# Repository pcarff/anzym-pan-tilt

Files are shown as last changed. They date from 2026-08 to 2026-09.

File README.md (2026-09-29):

# Dual-Axis Pan-Tilt (Alt-Azimuth) Stepper Controller

A professional dual-axis stepper motor controller and real-time dashboard for Pan-Tilt (Azimuth-Elevation) tracking and positioning systems. Built for Arduino Uno interfacing with **AutomationDirect SureStep STP-DRV-6575** microstepping drives.

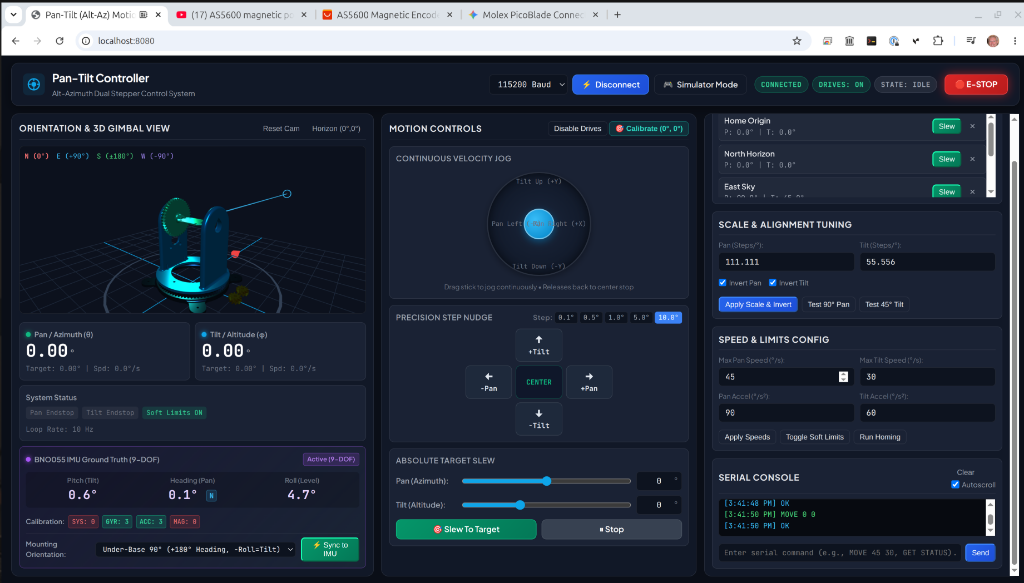
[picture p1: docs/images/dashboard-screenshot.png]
Pan-Tilt Controller Real-Time Dashboard


---

## 🌟 Key Features

- **Firmware (Arduino C++)**:
  - Smooth trapezoidal acceleration and velocity profiling.
  - Open-loop step position tracking with engineering degree ($^\circ$) unit conversion.
  - Continuous velocity jogging (interactive joystick control).
  - Configurable soft travel limits (prevent cable wrap / mechanical collisions).
  - Limit switch homing state machine with debounce.
  - Extensible sensor hooks for I2C IMU (MPU6050, BNO055) and auxiliary inputs.
  - 115200 baud ASCII serial protocol with high-frequency (10–20 Hz) telemetry streaming.
- **Dashboard (Web & Web Serial)**:
  - Direct USB Web Serial connection (no backend server required!).
  - Built-in **Simulator Mode** for instant interactive testing without hardware.
  - Interactive **3D Gimbal Visualizer** (Three.js) showing live physical orientation, compass heading, and target reticle.
  - **📐 2-Point Manual Calibration Studio**: Interactive visual wizard to position start reference, zero step counter, jog/nudge to target angle, calculate steps/deg & gear ratio, cross-check with BNO055 IMU ground truth, and apply live to controller RAM without resetting.
  - **Multi-Trial Averaging**: Run multiple calibration passes, compute mean scale & standard deviation ($\pm\sigma$), and apply statistically filtered values.
  - **2D Virtual Joystick** for smooth velocity jogging.
  - **Precision Step Nudge D-Pad** ($0.1^\circ, 0.5^\circ, 1.0^\circ, 5.0^\circ, 10.0^\circ$).
  - **Absolute Target Slew** with sliders and direct degree inputs.
  - **Waypoint & Preset Manager** with persistent browser storage.
  - **Integrated Serial Terminal** with command history.
  - Instant Emergency Stop (`E-STOP`).

---

## 🔌 Hardware Wiring Guide (STP-DRV-6575 & Arduino Uno)

### Pin Mapping Table

| Arduino Uno Pin | Function | STP-DRV-6575 Terminal | Notes |
|---|---|---|---|
| `D2` | Pan STEP (Pulse) | **STEP+** (Drive 1 - Pan) | 5V Step Pulse (Active High) |
| `D3` | Pan DIR (Direction) | **DIR+** (Drive 1 - Pan) | High = CW, Low = CCW |
| `D4` | Pan EN (Enable) | **EN+** (Drive 1 - Pan) | High = Energized, Low = Free |
| `D5` | Tilt STEP (Pulse) | **STEP+** (Drive 2 - Tilt) | 5V Step Pulse (Active High) |
| `D6` | Tilt DIR (Direction) | **DIR+** (Drive 2 - Tilt) | High = Up, Low = Down |
| `D7` | Tilt EN (Enable) | **EN+** (Drive 2 - Tilt) | High = Energized, Low = Free |
| `GND` | Common Ground | **STEP-**, **DIR-**, **EN-** (Both Drives) | Common Cathode wiring |
| `D8` | Pan Limit Switch | Switch NO $\to$ `D8`, Common $\to$ `GND` | Internal pull-up enabled |
| `D9` | Tilt Limit Switch | Switch NO $\to$ `D9`, Common $\to$ `GND` | Internal pull-up enabled |
| `A4` (SDA) | I2C Data | Future IMU / Sensors SDA | Optional |
| `A5` (SCL) | I2C Clock | Future IMU / Sensors SCL | Optional |

### STP-DRV-6575 DIP Switch Settings
- **Current (Amps)**: Set switches according to your stepper motor rated phase current.
- **Microstepping**: Recommended **8x microstepping** (1600 steps/rev) or **16x microstepping** (3200 steps/rev).
- Match the microstepping in [`firmware/PanTiltController/Config.h`](file:///workspaces/anzym_altaz_ws/firmware/PanTiltController/Config.h) (`PAN_MICROSTEPS` and `TILT_MICROSTEPS`).

---

## 🚀 Getting Started

### 1. Flashing the Arduino Firmware
1. Open the Arduino IDE.
2. Open [`firmware/PanTiltController/PanTiltController.ino`](file:///workspaces/anzym_altaz_ws/firmware/PanTiltController/PanTiltController.ino).
3. Select **Board**: `Arduino Uno` and choose your serial port.
4. Click **Upload**.

### 2. Launching the Dashboard
The dashboard runs entirely in the browser using the **Web Serial API** (Google Chrome, Microsoft Edge, Opera).

To run locally:
```bash
# Option A: Python simple HTTP server
python3 -m http.server 8080 --directory dashboard

# Option B: Node.js npx serve
npx serve dashboard
```
Then open `http://localhost:8080` in Chrome/Edge.

- Click **"Connect Serial"** to connect to your Arduino Uno.
- Or click **"Simulator Mode"** to test all 3D visuals, joystick controls, presets, and commands immediately without physical hardware!

---

## 📡 Serial Command Reference

Baud Rate: `115200` | Line Ending: `\n` or `\r\n`

| Command | Example | Description |
|---|---|---|
| `MOVE <pan> <tilt>` | `MOVE 45.0 15.0` | Move to absolute angles in degrees |
| `MOVEREL <d_pan> <d_tilt>` | `MOVEREL 1.0 -2.5` | Move relative by delta degrees |
| `JOG <p_spd> <t_spd>` | `JOG 20.0 -10.0` | Continuous velocity jog in deg/s (`JOG 0 0` to stop) |
| `STOP` | `STOP` | Decelerate to smooth stop |
| `ESTOP` | `ESTOP` | Immediate emergency stop and disable |
| `ENABLE` / `DISABLE` | `ENABLE` | Energize or de-energize stepper coils |
| `ZERO` | `ZERO` | Reset current position as $(0^\circ, 0^\circ)$ |
| `SETPOS <pan> <tilt>` | `SETPOS 0 45` | Set custom coordinate reference |
| `HOME [ALL\|PAN\|TILT]` | `HOME ALL` | Execute limit switch homing routine |
| `SET SPEED <p> <t>` | `SET SPEED 60 40` | Set max velocity in deg/s |
| `SET ACCEL <p> <t>` | `SET ACCEL 120 80` | Set acceleration in $\text{deg/s}^2$ |
| `SET LIMITS <ON\|OFF>` | `SET LIMITS ON` | Toggle soft travel limits |
| `GET POS` | `GET POS` | Returns `POS P=<pan> T=<tilt>` |
| `GET STATUS` | `GET STATUS` | Returns telemetry packet |
| `PING` | `PING` | Returns `PONG` |

### Telemetry Packet Format (Broadcast at 10 Hz)
```
STATUS P=12.50 T=-4.20 TP=12.50 TT=-4.20 SP=0.0 ST=0.0 MV=0 EN=1 LP=0 LT=0
```
- `P`, `T`: Current Pan and Tilt angles ($^\circ$)
- `TP`, `TT`: Target Pan and Tilt angles ($^\circ$)
- `SP`, `ST`: Current speed in deg/s
- `MV`: Moving flag (1 = active, 0 = idle)
- `EN`: Drive enable flag (1 = enabled, 0 = disabled)
- `LP`, `LT`: Pan and Tilt limit switch states (1 = triggered)

---

## 📐 Angular Scale & Precision Calibration Guide

> 📖 **Comprehensive Guide Available**: For full step-by-step procedures, multi-run statistical averaging, live dashboard wizard steps, and permanent firmware flashing instructions, see [docs/CALIBRATION_PROCEDURES.md](docs/CALIBRATION_PROCEDURES.md).

When tuning your pan-tilt platform to match the commanded degrees ($^\circ$) with 1:1 physical accuracy, use the following formulas:

### 1. Empirical Measurement Calibration Formula
If you command a move and measure the actual physical rotation using a digital angle gauge, protractor, or index mark:

$$\mathbf{S_{\text{new}} = S_{\text{current}} \times \left( \frac{\theta_{\text{commanded}}}{\theta_{\text{measured}}} \right)}$$

* $\mathbf{S_{\text{current}}}$: Current Steps/Degree setting in dashboard (e.g. `111.111`).
* $\mathbf{\theta_{\text{commanded}}}$: Commanded target angle in degrees (e.g. `90.0°` or `360.0°`).
* $\mathbf{\theta_{\text{measured}}}$: Actual physical angle rotated as measured on the platform.
* $\mathbf{S_{\text{new}}}$: Exact calibrated Steps/Degree to enter into the dashboard or `Config.h`.

#### Calibration Example:
1. Current setting: **$111.111\text{ steps/deg}$**.
2. You click **"Test 90° Pan"** ($\theta_{\text{commanded}} = 90^\circ$).
3. You measure the physical platform rotated **$86.5^\circ$** ($\theta_{\text{measured}} = 86.5^\circ$).
4. Calculate:
   $$S_{\text{new}} = 111.111 \times \left(\frac{90.0}{86.5}\right) = \mathbf{115.606\text{ steps/degree}}$$
5. Enter **`115.606`** into the **Pan (Steps/°)** box in the dashboard and click **Apply Scale**.

---

### 2. Theoretical Mechanical Formula (From Gear Ratios)

$$\mathbf{\text{Steps per Degree} = \frac{\text{Motor Steps/Rev} \times \text{Microstepping} \times \text{Gear Ratio}}{360^\circ}}$$

For our configuration:
* **Wantai Motor**: $200\text{ full steps / rev}$ ($1.8^\circ/\text{step}$).
* **STP-DRV-6575 Drive**: $10\times\text{ microstepping}$ ($2,000\text{ steps / motor rev}$).

$$\mathbf{\text{Steps per Degree} = \frac{2,000 \times \text{Gear Ratio}}{360^\circ} = \frac{50}{9} \times \text{Gear Ratio} \approx 5.55556 \times \text{Gear Ratio}}$$

| Gear Ratio | Steps per Degree ($^\circ$) | Microsteps per 90° Quarter Turn |
|:---:|:---:|:---:|
| **1:1** (Direct Drive) | `5.556` | 500 steps |
| **5:1** (e.g. 16T to 80T belt) | `27.778` | 2,500 steps |
| **10:1** (e.g. 16T to 160T belt) | `55.556` | 5,000 steps |
| **16:1** | `88.889` | 8,000 steps |
| **18:1** | `100.000` | 9,000 steps |
| **20:1** | `111.111` | 10,000 steps |
| **24:1** | `133.333` | 12,000 steps |
| **30:1** | `166.667` | 15,000 steps |
| **36:1** | `200.000` | 18,000 steps |

---

### 3. High-Precision 360° Full-Turn Calibration Method
1. Place a piece of tape on the rotating platform and stationary base with a fine pen line aligned at $0^\circ$.
2. Command a full $360.0^\circ$ rotation:
   * Send `MOVE 360 0` in the serial console (or `MOVEREL 360 0`).
3. If the line finishes short or past the mark, note the angle difference and apply the empirical formula. Over $360^\circ$, errors are multiplied by 4, giving sub-0.05° precision!

---

## 🧭 Bosch BNO055 9-DOF IMU Sensor Integration

The system integrates an **Adafruit Bosch BNO055 9-DOF Absolute Orientation Sensor** to provide absolute "ground truth" elevation (Tilt) and compass azimuth (Pan) tracking independent of open-loop stepper pulse counts.

```
+-------------------------------------------------------------------------------+
|                             SYSTEM DATA FLOW                                  |
|                                                                               |
|  [BNO055 IMU] --(I2C: A4/A5)--> [SensorManager] --(Serial: 115200)--> [Web]  |
|   - Accel (3-axis)               - Non-blocking 10Hz    STATUS IP=...   - UI  |
|   - Gyro  (3-axis)               - EMI Motion Lockout   IR=... IY=...   - 3D  |
|   - Mag   (3-axis)               - TWI Stop-Start Cond. IC=3,3,3,3      - Sync|
+-------------------------------------------------------------------------------+
```

### Sensor Specifications & Operation
- **Onboard Fusion Processor**: 32-bit ARM Cortex-M0 running Bosch Sensortec BSX3.0 Fusion software.
- **Operating Modes**:
  - `BNO055_OPR_IMUPLUS` (`0x08`): 6-DOF fusion (Accelerometer + Gyroscope). Highly immune to nearby ferrous metals and motor magnetic fields, providing rapid, rock-solid relative pitch, roll, and relative heading.
  - `BNO055_OPR_NDOF` (`0x0C`): Full 9-DOF absolute fusion with geomagnetic magnetometer referenced to Magnetic North.
- **Wiring (Arduino Uno)**:
  - `Vin` $\to$ `5V`
  - `GND` $\to$ `GND`
  - `SDA` $\to$ `A4` (I2C Data)
  - `SCL` $\to$ `A5` (I2C Clock)
  - `RST` $\to$ Left floating (software reset via register `0x3F`)

---

### Engineering Challenges & Adaptations

During development and testing on the dual-axis testbed, several hardware and physical constraints were diagnosed and resolved:

#### 1. I2C Bus Hang & Clock-Stretching Mitigation
- **The Problem**: The BNO055's internal Cortex-M0 processor stretches the I2C clock line (SCL LOW) while computing sensor fusion algorithms. On the ATmega328P, standard repeated-start conditions (`Wire.endTransmission(false)`) can cause the hardware TWI peripheral to lock in an unrecoverable state, causing all subsequent reads to return `0x00` or timeout.
- **The Fix**: Rewrote the register read routines in [`BNO055_Driver.cpp`](file:///workspaces/anzym_altaz_ws/firmware/PanTiltController/BNO055_Driver.cpp) to use clean **STOP conditions** (`Wire.endTransmission(true)`) followed by fresh START requests. The BNO055 auto-increments internal register pointers across burst reads even after a STOP.
- **Bus Reinitialization Guard**: Separated `Wire.begin()` and `Wire.setClock(100000)` into `SensorManager::init()` so it is called strictly once.

#### 2. Stepper Motor High-Frequency EMI Immunity
- **The Problem**: While the stepper drives are executing high-speed moves or multi-axis slewing, high-frequency optocoupler switching and motor phase current pulses induce electrical noise on adjacent I2C breadboard wires (A4/A5). This caused I2C packets during slews to get corrupted to all zeros.
- **The Fix**: Implemented **Motion-Aware EMI Lockout** in [`SensorManager::updateAuxSensors()`](file:///workspaces/anzym_altaz_ws/firmware/PanTiltController/SensorManager.cpp). When `motion.isMoving()` is true, I2C reads are suspended and the dashboard holds the last validated orientation. As soon as the step pulses complete and the motors settle, live I2C sampling resumes instantly.

#### 3. Under-Base Inverted & Sideways Mounting Transformation
- **The Problem**: The sensor is mounted on the underside of the tilt bracket, rotated 90° sideways.
  1. Mounting upside down inverts the vertical Z-axis.
  2. Facing backward swaps North and South (180° rotation), causing West to read East ($90^\circ$ vs $270^\circ$).
  3. Sideways orientation swaps the Pitch and Roll measurement axes.
- **The Fix**: Implemented the **Under-Base 90° (+180° Heading, -Roll = Tilt)** transformation in [`dashboard/src/app.js`](file:///workspaces/anzym_altaz_ws/dashboard/src/app.js):
  $$\text{Pitch}_{\text{Tilt}} = -\text{Roll}_{\text{raw}}$$
  $$\text{Roll}_{\text{Level}} = -\text{Pitch}_{\text{raw}}$$
  $$\text{Heading}_{\text{Pan}} = (\text{Yaw}_{\text{raw}} + 180^\circ) \pmod{360^\circ}$$
- **Result**: Panning `Pan-` decreases heading naturally towards West ($270^\circ\ \text{W}$), panning `Pan+` increases heading towards East ($90^\circ\ \text{E}$), and tilting up produces positive elevation ($0^\circ \to +90^\circ$).

#### 4. Absolute One-Click Alignment (`⚡ Sync to IMU`)
- The dashboard includes a **Sync to IMU** button that automatically normalizes the $0^\circ..360^\circ$ compass azimuth to the controller's $[-180^\circ, +180^\circ]$ soft limit coordinate frame and commands `SETPOS <pan> <tilt>`, instantly establishing ground-truth zero without mechanical homing.

---

## 📡 Serial Telemetry & Diagnostic Commands

### Extended Telemetry Packet Format (10 Hz Stream)
```
STATUS P=0.00 T=0.00 TP=0.00 TT=0.00 SP=0.0 ST=0.0 MV=0 EN=1 LP=0 LT=0 IP=45.10 IR=0.20 IY=270.00 IC=3,3,3,3
```
- `IP`: IMU Ground Truth Pitch ($^\circ$)
- `IR`: IMU Ground Truth Roll ($^\circ$)
- `IY`: IMU Ground Truth Yaw / Heading ($0.00^\circ$ to $360.00^\circ$)
- `IC`: Calibration status matrix `sys,gyro,accel,mag` (values $0$ to $3$, where $3 = \text{Fully Calibrated}$)

### Diagnostic Commands
- **`GET IMU`**: Queries sensor hardware status and registers directly:
  ```
  IMU AVAIL=1 CHIP=0xA0 MODE=0x8 SYS=0x0 ERR=0x0 P=45.10 R=0.20 Y=270.00 CAL=3,3,3,3
  ```
- **`SYNC IMU`**: Firmware-level position synchronization with IMU Euler registers.

---

## 🧪 Testing and Verification
Unit tests for the motion profiling algorithms, soft limits, coordinate transformations, BNO055 I2C mocks, and command parser can be executed locally:
```bash
npm run test:firmware
```
To compile and upload firmware:
```bash
npm run build:firmware   # Compile Arduino Uno hex with arduino-builder
npm run flash            # Flash to /dev/ttyACM0 via avrdude
```

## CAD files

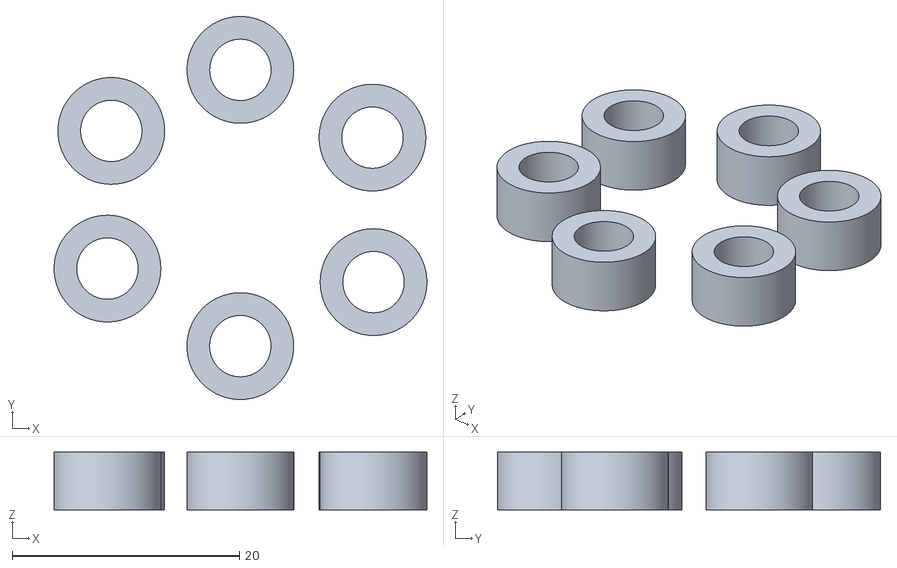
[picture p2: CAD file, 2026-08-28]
dashboard/models/Turret_bushings.stl
32.8 x 33.7 x 5.10

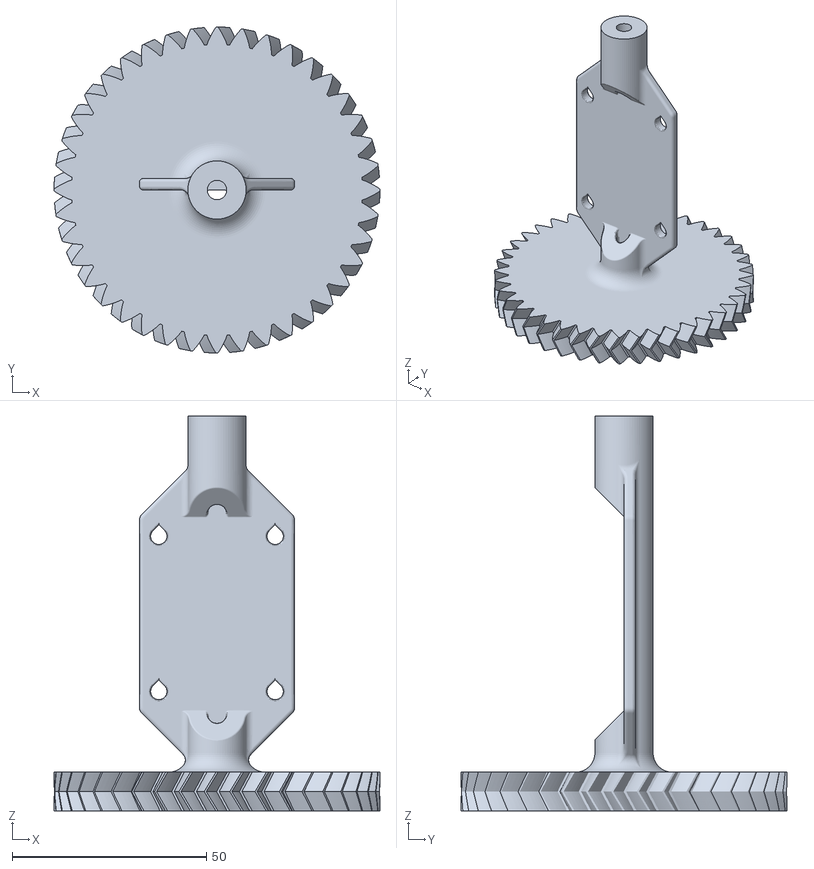
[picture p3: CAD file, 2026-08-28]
dashboard/models/Turret_Shaft.stl
84.0 x 84.0 x 101.8

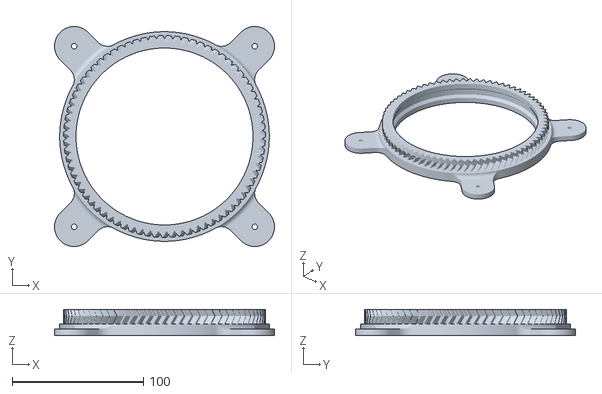
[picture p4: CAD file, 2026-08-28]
dashboard/models/Turret_base.stl
167.9 x 167.9 x 20.0

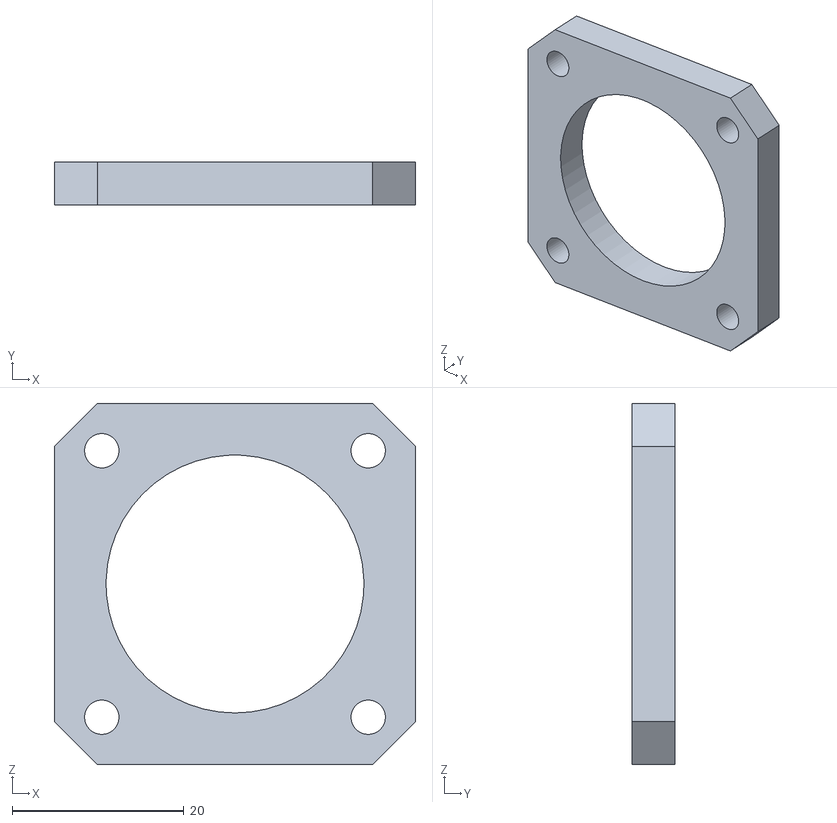
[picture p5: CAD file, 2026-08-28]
dashboard/models/NEMA_motor_spacer.STL
42.0 x 5.00 x 42.0

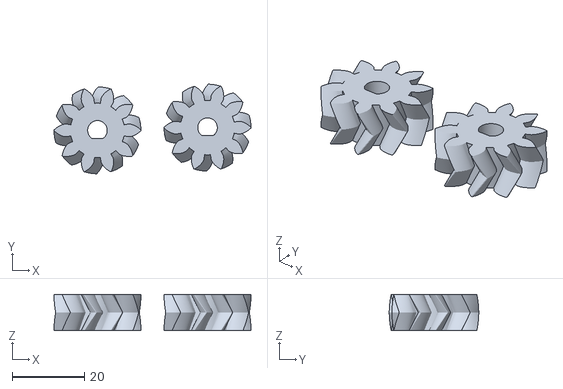
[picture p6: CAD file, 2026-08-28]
dashboard/models/Turret_stepper_gears.stl
54.4 x 24.7 x 10.0

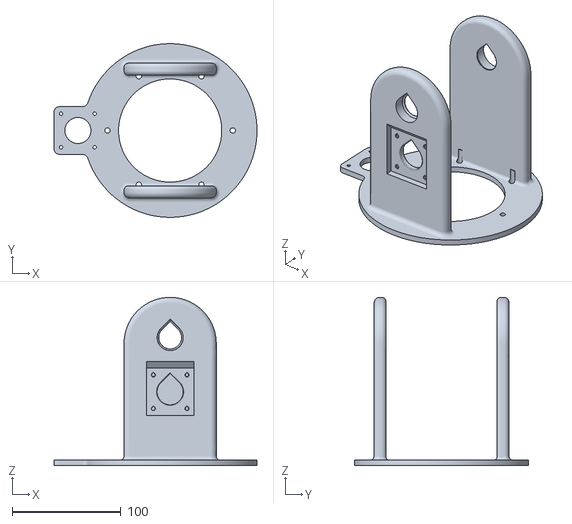
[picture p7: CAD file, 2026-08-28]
dashboard/models/Turret_top.stl
187.0 x 160.0 x 155.0

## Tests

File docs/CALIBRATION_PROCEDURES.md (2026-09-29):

# Dual-Axis Pan-Tilt Calibration Procedures & Operations Guide

This comprehensive reference document outlines the physical calibration procedures, operating methodologies, and permanent firmware flashing steps for the **Dual-Axis Alt-Azimuth (Pan-Tilt) Stepper Platform** powered by the **Arduino Uno**, **AutomationDirect SureStep STP-DRV-6575** drives, and **Bosch BNO055 9-DOF Absolute IMU**.

---

## 📑 Table of Contents

1. [System Architecture & Mathematics](#1-system-architecture--mathematics)
2. [Method 1: Interactive 2-Point Manual Calibration Studio (Web Dashboard)](#2-method-1-interactive-2-point-manual-calibration-studio-web-dashboard)
   - [Overview & Advantage](#overview--advantage)
   - [Step-by-Step Procedure](#step-by-step-procedure)
   - [Multi-Trial Averaging & Statistical Analysis](#multi-trial-averaging--statistical-analysis)
   - [Live Scale Injection Protocol](#live-scale-injection-protocol)
3. [Method 2: Automated Multi-Run IMU Ground-Truth Calibration (CLI)](#3-method-2-automated-multi-run-imu-ground-truth-calibration-cli)
   - [Prerequisites & Port Arbitration](#prerequisites--port-arbitration)
   - [Running the 10-Iteration Calibration](#running-the-10-iteration-calibration)
   - [Forward-Reverse Backlash Compensation](#forward-reverse-backlash-compensation)
4. [Permanent Firmware Configuration & Flashing](#4-permanent-firmware-configuration--flashing)
   - [Editing `Config.h`](#editing-configh)
   - [Unit Test Verification](#unit-test-verification)
   - [Compiling & Flashing via avrdude](#compiling--flashing-via-avrdude)
5. [Post-Reboot Resumption Checklist](#5-post-reboot-resumption-checklist)

---

## 1. System Architecture & Mathematics

### Hardware Baseline
* **Motors**: 2-Phase Hybrid Stepper Motors, $200\text{ full steps / revolution}$ ($1.8^\circ/\text{step}$).
* **Drivers**: AutomationDirect STP-DRV-6575 microstepping drives set to **10× microstepping** ($2,000\text{ pulses / motor rev}$).
* **Sensors**: Bosch BNO055 9-DOF IMU mounted under-base, running BSX3.0 sensor fusion via hardware I2C (pins `A4`/`A5`).
* **Microcontroller**: Arduino Uno running custom real-time trapezoidal motion firmware at 115,200 baud.

### The Governing Gear Ratio & Step Relationship

$$\text{Steps per Revolution (Axis)} = \text{Steps per Degree} \times 360^\circ$$

$$\text{Gear Reduction Ratio} = \frac{\text{Steps per Revolution}}{2,000\text{ steps/motor rev}} = \frac{\text{Steps per Degree} \times 360^\circ}{2,000}$$

$$\text{Calibrated Scale } (S_{\text{new}}) = \frac{\Delta\text{ Motor Pulse Steps Counted}}{\Delta\text{ True Physical Angle Measured } (^\circ)}$$

* **Pan Baseline**: Nominal 19.826:1 ratio $\to \mathbf{110.145\text{ steps/degree}}$ ($39,652\text{ steps/rev}$).
* **Tilt Baseline**: Nominal 10.668:1 ratio $\to \mathbf{59.267\text{ steps/degree}}$ ($21,336\text{ steps/rev}$).

---

## 2. Method 1: Interactive 2-Point Manual Calibration Studio (Web Dashboard)

### Overview & Advantage
The **2-Point Manual Calibration Studio** is embedded directly within the Web Serial dashboard (`http://localhost:8080`). It provides a complete visual wizard that allows you to:
1. Jog or nudge the platform to a physical zero mark and lock the reference counter.
2. Slew or nudge to a known physical reference angle ($30^\circ$, $45^\circ$, $90^\circ$, $180^\circ$, or custom).
3. Record the end position, compute steps/deg, steps/rev, and gear ratio, and cross-check against the live BNO055 IMU ground truth.
4. Apply the calculated scale directly to the live controller RAM (`SET SCALE`) without losing serial connection or rebooting.
5. Record multiple trials to compute a running mean and standard deviation ($\pm\sigma$).

---

### Step-by-Step Procedure

#### Step A: Launch the Web Dashboard
1. Open a terminal in the project root:
   ```bash
   python3 -m http.server 8080 --directory dashboard
   ```
2. Open **Google Chrome**, **Microsoft Edge**, or an Chromium-based browser supporting the Web Serial API at:
   ```
   http://localhost:8080
   ```
3. Click **"Connect Serial"** in the top-right header and select your Arduino Uno port (`/dev/ttyACM0` or `/dev/ttyUSB0`) at 115200 baud. *(Alternatively, click "Simulator Mode" if testing offline).*

#### Step B: Open the Calibration Studio
1. Click the **`📐 2-Point Calibration Studio`** button in the top navigation bar (or in the System Status panel).
2. Select the target axis tab:
   - **`Pan Axis (Azimuth)`**
   - **`Tilt Axis (Altitude)`**
3. Notice the **Active Scale** banner displays the current steps/degree and steps/revolution active in controller memory.

#### Step C: Step 1 — Set Starting Reference
1. Position the axis to your physical start mark (such as a mechanical index pointer, level mark, or external protractor):
   - Use the **Fine Nudge** buttons (`-10°`, `-1°`, `-0.1°`, `+0.1°`, `+1°`, `+10°`) inside the dialog.
   - Or click **`🔓 Release Motor Coils (Hand Move)`** to de-energize the STP-DRV-6575 holding torque and turn the gimbal by hand, then lock coils again. *(Note: Because STP-DRV-6575 is open-loop, use the fine nudge buttons for the actual measured displacement so the controller counts pulse steps).*
2. Click **`📌 Zero Counter & Set Start Reference`**.
3. **Verified Outcome**:
   - The controller sends `ZERO` to the Arduino.
   - The Elapsed Motor Steps counter resets to `+0 STEPS`.
   - The start status changes to green: `✓ Zero reference set at 0.00° (IMU: X.X°)`.
   - The Step 2 card glows cyan, signaling ready for target movement.

#### Step D: Step 2 — Move to Target & Calculate
1. Slew or nudge the axis from the zero mark to your desired target reference angle (for example, exactly $90.0^\circ$ or $180.0^\circ$).
2. Enter the physical displacement angle:
   - Click one of the quick preset buttons: **`30°`**, **`45°`**, **`90°`**, or **`180°`**.
   - Or type a custom angle into the **Target Angle (°)** input.
   - *Optional*: Check **"Use live BNO055 IMU angle as target"** if you want the high-precision BNO055 sensor fusion delta to serve as the ground truth angle automatically.
3. Click **`🎯 Record Position & Calculate Steps`**.

#### Step E: Review Results & Apply
The **Calculation Result** card will appear with computed metrics:
* **Calibrated Steps / Degree**: $\text{Scale} = \frac{\text{Elapsed Steps}}{\text{Target Angle}}$
* **Steps / Full Rev (360°)**: $\text{Steps/Deg} \times 360$
* **Calculated Gear Ratio**: $\frac{\text{Steps/Rev}}{2,000} : 1$
* **Steps Issued / Angle**: Exact step pulse count and commanded angle.
* **IMU Ground Truth Check**: Real-time angular delta reported by the BNO055 IMU and deviation from target.

**Actions Available**:
* **`⚡ Apply Scale to Live Controller`**: Transmits `SET SCALE <pan> <tilt>` over Web Serial directly into Arduino RAM. The system immediately adopts the new scale without losing position.
* **`➕ Add to Trial Average`**: Adds the trial to the calibration history table for multi-run averaging.

---

### Multi-Trial Averaging & Statistical Analysis
To achieve sub-0.05° tracking precision across gear manufacturing tolerances and belt tension variations:
1. Repeat the calibration sequence **3 to 10 times** in alternating directions (clockwise and counterclockwise).
2. After each run, click **`➕ Add to Trial Average`**.
3. The **Calibration Trial History** table records:
   - Trial Number & Timestamp
   - Axis (Pan vs. Tilt)
   - Target Angle ($^\circ$)
   - Steps Taken
   - Measured Scale ($\text{steps/deg}$)
   - IMU Delta Confirmation
4. The **Running Average Summary Bar** automatically computes:
   - **Running Average Scale**: Arithmetic mean $\mu = \frac{1}{N}\sum_{i=1}^N S_i$
   - **Standard Deviation**: $\sigma = \sqrt{\frac{1}{N}\sum_{i=1}^N (S_i - \mu)^2}$ and relative percentage error
   - **Total Trials Count**
5. Click **`⚡ Apply Averaged Scale`** to commit the statistically filtered scale to the live controller.

---

## 3. Method 2: Automated Multi-Run IMU Ground-Truth Calibration (CLI)

### Prerequisites & Port Arbitration
> [!IMPORTANT]
> The Web Serial API in Chrome holds an exclusive lock on `/dev/ttyACM0`. Before running CLI Python scripts, click **Disconnect** in the web dashboard or close the browser tab.

Check port availability:
```bash
ls -l /dev/ttyACM*
```

### Running the 10-Iteration Calibration
The repository contains standalone automated Python calibration routines:
* [`calibrate_10x.py`](file:///workspaces/anzym_altaz_ws/calibrate_10x.py): Executes 10 consecutive $90^\circ$ and $180^\circ$ calibration cycles on both Pan and Tilt axes, queries IMU Euler orientation registers, and computes the aggregate statistical mean.
* [`calibrate_dual_axis_imu.py`](file:///workspaces/anzym_altaz_ws/calibrate_dual_axis_imu.py): Interactive dual-axis testing harness.

To execute the 10-run automated calibration:
```bash
python3 calibrate_10x.py
```

### Forward-Reverse Backlash Compensation
The script executes moves in alternating pairs:
1. Move Forward $+90.0^\circ$ $\to$ Measure IMU delta $\to$ Calculate Scale.
2. Move Reverse $-90.0^\circ$ $\to$ Measure IMU delta $\to$ Calculate Scale.
3. Move Forward $+180.0^\circ$ $\to$ Measure IMU delta $\to$ Calculate Scale.
4. Move Reverse $-180.0^\circ$ $\to$ Measure IMU delta $\to$ Calculate Scale.

By averaging positive and negative displacement runs, any mechanical gear backlash cancels out of the scale coefficient.

---

## 4. Permanent Firmware Configuration & Flashing

Once the desired scale is verified in the dashboard or via Python, bake the values permanently into the Arduino Uno's flash memory.

### Editing `Config.h`
Open [`firmware/PanTiltController/Config.h`](file:///workspaces/anzym_altaz_ws/firmware/PanTiltController/Config.h) and update lines 50–57 with your calibrated gear ratios:

```cpp
// Mechanical Gear Reduction (Motor revs per 1 axis rev. 1.0 for direct drive)
#define PAN_GEAR_RATIO            19.826f // Calibrated Average (110.145 steps/deg, 39,652 steps/rev)
#define TILT_GEAR_RATIO           10.668f // Calibrated Average (59.267 steps/deg, 21,336 steps/rev)

// Calculated Steps per Degree
// steps_per_deg = (steps_per_rev * microsteps * gear_ratio) / 360.0
#define PAN_STEPS_PER_DEG         ((PAN_MOTOR_STEPS_PER_REV * PAN_MICROSTEPS * PAN_GEAR_RATIO) / 360.0f)
#define TILT_STEPS_PER_DEG        ((TILT_MOTOR_STEPS_PER_REV * TILT_MICROSTEPS * TILT_GEAR_RATIO) / 360.0f)
```

### Unit Test Verification
Before flashing physical hardware, run the C++ unit test suite to ensure motion profiles and soft limit clamping remain 100% compliant:
```bash
npm run test:firmware
```
Expected output:
```
========================================
Starting Pan-Tilt Firmware Unit Tests
========================================
[TEST] Running MotionController tests...
  ✓ Position move reached: Pan=45.0045°, Tilt=30°
  ✓ Soft limits successfully clamped tilt to 90°
  ✓ Jog and smooth deceleration verified
  ✓ Emergency stop verified
[TEST] Running CommandParser tests...
  ✓ PING -> PONG acknowledged
  ✓ MOVE 15.5 -10.0 parsed and executed
  ✓ JOG command executed
  ✓ STOP command executed
  ✓ GET STATUS returned valid telemetry
  ✓ ZERO command reset coordinates
========================================
ALL FIRMWARE TESTS PASSED SUCCESSFULLY! ✓
========================================
```

### Compiling & Flashing via avrdude
Ensure serial terminals/browsers are disconnected, then run:
```bash
./upload_firmware.sh
```
Or manually via Arduino CLI:
```bash
arduino-cli compile --fqbn arduino:avr:uno firmware/PanTiltController -e
avrdude -v -p atmega328p -c arduino -P /dev/ttyACM0 -b 115200 -D -U flash:w:build/firmware/PanTiltController.ino.hex:i
```

---

## 5. Post-Reboot Resumption Checklist

When restarting this computer to apply system updates, resume your tracking environment with this 3-step checklist:

1. **Verify Serial Device Recognition**:
   ```bash
   ls -l /dev/ttyACM*
   ```
   *(If permission is denied: `sudo usermod -a -G dialout $USER` and log back in).*

2. **Start the Web Dashboard**:
   ```bash
   cd /workspaces/anzym_altaz_ws
   python3 -m http.server 8080 --directory dashboard
   ```

3. **Connect & Zero Hardware**:
   - Open `http://localhost:8080` in Google Chrome or Microsoft Edge.
   - Click **Connect Serial** $\to$ select the Arduino Uno port.
   - Click **`⚡ Sync to IMU`** or **`🎯 Calibrate (0°, 0°)`** to initialize coordinates.
   - Launch **`📐 2-Point Calibration Studio`** at any time to inspect or re-tune axis scales.

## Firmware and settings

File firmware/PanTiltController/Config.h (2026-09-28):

#ifndef CONFIG_H
#define CONFIG_H

#include <Arduino.h>

// ============================================================================
// HARDWARE PIN ASSIGNMENTS (Arduino Uno)
// ============================================================================

// Pan Axis (Azimuth / Yaw) - Connected to STP-DRV-6575 Drive #1
#define PIN_PAN_STEP          2     // Step / Pulse output (Active HIGH)
#define PIN_PAN_DIR           3     // Direction output
#define PIN_PAN_ENABLE        4     // Enable output (Optional, STP-DRV-6575 EN input)

// Tilt Axis (Altitude / Pitch) - Connected to STP-DRV-6575 Drive #2
#define PIN_TILT_STEP         5     // Step / Pulse output (Active HIGH)
#define PIN_TILT_DIR          6     // Direction output
#define PIN_TILT_ENABLE       7     // Enable output (Optional, STP-DRV-6575 EN input)

// Endstop / Limit Switches (Optional)
#define PIN_PAN_LIMIT         8     // Pan Home/Limit switch (Active LOW with internal pull-up)
#define PIN_TILT_LIMIT        9     // Tilt Home/Limit switch (Active LOW with internal pull-up)

// Auxiliary & Status
#define PIN_STATUS_LED        13    // On-board LED indicator
#define PIN_I2C_SDA           A4    // I2C Data for future sensors (MPU6050, BNO055, etc.)
#define PIN_I2C_SCL           A5    // I2C Clock for future sensors

// ============================================================================
// STEPPER MOTOR & DRIVE CONFIGURATION (STP-DRV-6575)
// ============================================================================

// Signal polarity for STP-DRV-6575 optoisolated inputs
// In common-cathode wiring: STEP-, DIR-, EN- to GND; STEP+, DIR+, EN+ to Arduino pins.
#define STEP_PULSE_ACTIVE_HIGH  true
#define DIR_INVERT_PAN          true   // Inverted per physical platform test
#define DIR_INVERT_TILT         true   // Inverted per physical platform test
#define ENABLE_ACTIVE_LOW       true   // STP-DRV-6575: LOW (opto off) = ENABLED, HIGH (opto on) = DISABLED
// Minimum pulse width in microseconds required by STP-DRV-6575 (spec min is 1.0 us, 2-5 us is safe)
#define STEP_PULSE_WIDTH_US     5

// Motor physical specs
#define PAN_MOTOR_STEPS_PER_REV   200.0f  // 1.8 degree stepper
#define TILT_MOTOR_STEPS_PER_REV  200.0f  // 1.8 degree stepper

// STP-DRV-6575 Microstepping switch setting (10x = 2,000 steps/rev)
#define PAN_MICROSTEPS            10.0f   // 2,000 steps/rev (SW5=OFF, SW6=ON, SW7=OFF)
#define TILT_MICROSTEPS           10.0f   // 2,000 steps/rev

// Mechanical Gear Reduction (Motor revs per 1 axis rev. 1.0 for direct drive)
#define PAN_GEAR_RATIO            19.826f // 10-Run Calibrated Average (110.145 steps/deg, 39,652 steps/rev)
#define TILT_GEAR_RATIO           10.668f // 10-Run Calibrated Average (59.267 steps/deg, 21,336 steps/rev)

// Calculated Steps per Degree
// steps_per_deg = (steps_per_rev * microsteps * gear_ratio) / 360.0
#define PAN_STEPS_PER_DEG         ((PAN_MOTOR_STEPS_PER_REV * PAN_MICROSTEPS * PAN_GEAR_RATIO) / 360.0f)
#define TILT_STEPS_PER_DEG        ((TILT_MOTOR_STEPS_PER_REV * TILT_MICROSTEPS * TILT_GEAR_RATIO) / 360.0f)

// ============================================================================
// MOTION DEFAULTS & TRAVEL LIMITS (in Degrees)
// ============================================================================

// Default & Maximum Velocities (Degrees / sec)
#define DEFAULT_MAX_SPEED_PAN     45.0f   // deg/sec
#define DEFAULT_MAX_SPEED_TILT    30.0f   // deg/sec
#define ABSOLUTE_MAX_SPEED_PAN    180.0f  // Upper safety clamp
#define ABSOLUTE_MAX_SPEED_TILT   120.0f  // Upper safety clamp

// Default Acceleration (Degrees / sec^2)
#define DEFAULT_ACCEL_PAN         90.0f   // deg/sec^2
#define DEFAULT_ACCEL_TILT        60.0f   // deg/sec^2

// Soft Travel Limits (in Degrees)
#define SOFT_LIMITS_ENABLED       true
#define PAN_MIN_DEG               -180.0f
#define PAN_MAX_DEG               180.0f
#define TILT_MIN_DEG              -45.0f  // Below horizon
#define TILT_MAX_DEG              90.0f   // Zenith (straight up)

// Homing Speeds & Direction
#define HOMING_SPEED_PAN          15.0f   // deg/sec
#define HOMING_SPEED_TILT         10.0f   // deg/sec
#define HOMING_TIMEOUT_MS         15000   // 15 seconds max homing timeout

// ============================================================================
// COMMUNICATION & TELEMETRY
// ============================================================================

#define SERIAL_BAUD_RATE          115200
#define SERIAL_RX_BUFFER_SIZE     128

// Telemetry streaming frequency (Hz). Set to 0 to disable auto-streaming.
#define DEFAULT_TELEMETRY_RATE_HZ 10      // 10 Hz = every 100 ms

#endif // CONFIG_H

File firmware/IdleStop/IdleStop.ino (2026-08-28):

#include <Arduino.h>

void setup() {
    pinMode(2, OUTPUT); digitalWrite(2, LOW);
    pinMode(3, OUTPUT); digitalWrite(3, LOW);
    pinMode(4, OUTPUT); digitalWrite(4, LOW);
    pinMode(5, OUTPUT); digitalWrite(5, LOW);
    pinMode(6, OUTPUT); digitalWrite(6, LOW);
    pinMode(7, OUTPUT); digitalWrite(7, LOW);
    pinMode(13, OUTPUT); digitalWrite(13, LOW);
    Serial.begin(115200);
    Serial.println(F("[SYSTEM] Stopped / Idle"));
}

void loop() {
    delay(1000);
}

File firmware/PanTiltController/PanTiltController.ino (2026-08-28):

/**
 * PanTiltController.ino
 * 
 * Dual-axis Pan-Tilt (Alt-Azimuth) Stepper Motor Controller
 * Hardware: Arduino Uno + STP-DRV-6575 Stepper Drives
 * 
 * Provides smooth trapezoidal acceleration, velocity jogging, soft limits,
 * limit switch homing, sensor integration hooks, and high-speed serial telemetry.
 */

#include "Config.h"
#include "MotionController.h"
#include "SensorManager.h"
#include "CommandParser.h"

// Global Controller Instances
MotionController motion;
SensorManager sensors;
CommandParser parser;

// Status LED blinker
unsigned long lastBlinkMillis = 0;
bool ledState = false;

void setup() {
    // 1. Initialize serial communication
    parser.init();
    Serial.println(F("=== Pan-Tilt Controller Initialized ==="));
    Serial.print(F("Pan steps/deg: "));
    Serial.print(PAN_STEPS_PER_DEG, 3);
    Serial.print(F(" | Tilt steps/deg: "));
    Serial.println(TILT_STEPS_PER_DEG, 3);

    // 2. Initialize hardware modules
    motion.init();
    sensors.init();

    // 3. Signal readiness with LED blink
    pinMode(PIN_STATUS_LED, OUTPUT);
    for (int i = 0; i < 3; i++) {
        digitalWrite(PIN_STATUS_LED, HIGH);
        delay(60);
        digitalWrite(PIN_STATUS_LED, LOW);
        delay(60);
    }
}

void loop() {
    // High-priority non-blocking step generation & motion updates
    motion.update();

    // Sensor debouncing & homing state machine
    sensors.update(motion);

    // Incoming serial command parsing & telemetry output
    parser.processSerial(motion, sensors);

    // Heartbeat LED: Fast blink when moving, slow pulse when idle
    unsigned long now = millis();
    unsigned long blinkInterval = motion.isMoving() ? 100 : 800;
    if (now - lastBlinkMillis >= blinkInterval) {
        lastBlinkMillis = now;
        ledState = !ledState;
        digitalWrite(PIN_STATUS_LED, ledState ? HIGH : LOW);
    }
}

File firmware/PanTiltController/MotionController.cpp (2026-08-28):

#include "MotionController.h"
#include <math.h>

MotionController::MotionController() : drivesEnabled(true), softLimitsActive(SOFT_LIMITS_ENABLED) {
}

void MotionController::init() {
    initAxis(panAxis, PIN_PAN_STEP, PIN_PAN_DIR, PIN_PAN_ENABLE,
             DIR_INVERT_PAN, PAN_STEPS_PER_DEG, DEFAULT_MAX_SPEED_PAN,
             DEFAULT_ACCEL_PAN, PAN_MIN_DEG, PAN_MAX_DEG);

    initAxis(tiltAxis, PIN_TILT_STEP, PIN_TILT_DIR, PIN_TILT_ENABLE,
             DIR_INVERT_TILT, TILT_STEPS_PER_DEG, DEFAULT_MAX_SPEED_TILT,
             DEFAULT_ACCEL_TILT, TILT_MIN_DEG, TILT_MAX_DEG);

    setEnabled(true);
}

void MotionController::initAxis(AxisState &axis, uint8_t stepPin, uint8_t dirPin, uint8_t enablePin, 
                                bool dirInvert, float stepsPerDeg, float maxSpeed, float accel, 
                                float minLim, float maxLim) {
    axis.stepPin = stepPin;
    axis.dirPin = dirPin;
    axis.enablePin = enablePin;
    axis.dirInvert = dirInvert;

    axis.currentStep = 0;
    axis.targetStep = 0;

    axis.currentSpeedDeg = 0.0f;
    axis.targetSpeedDeg = 0.0f;
    axis.maxSpeedDeg = maxSpeed;
    axis.accelDeg = accel;

    axis.stepsPerDeg = stepsPerDeg;
    axis.minLimitDeg = minLim;
    axis.maxLimitDeg = maxLim;

    axis.mode = MODE_IDLE;
    axis.direction = 0;

    axis.lastStepMicros = micros();
    axis.stepIntervalMicros = 1000000UL;
    axis.lastProfileUpdateMicros = micros();

    axis.stepPinHigh = false;
    axis.stepPulseStartMicros = 0;

    pinMode(axis.stepPin, OUTPUT);
    pinMode(axis.dirPin, OUTPUT);
    pinMode(axis.enablePin, OUTPUT);

    digitalWrite(axis.stepPin, LOW);
    digitalWrite(axis.dirPin, LOW);
}

void MotionController::setEnabled(bool enable) {
    drivesEnabled = enable;
    uint8_t state = enable ? (ENABLE_ACTIVE_LOW ? LOW : HIGH) : (ENABLE_ACTIVE_LOW ? HIGH : LOW);
    digitalWrite(panAxis.enablePin, state);
    digitalWrite(tiltAxis.enablePin, state);

    if (!enable) {
        panAxis.mode = MODE_IDLE;
        tiltAxis.mode = MODE_IDLE;
        panAxis.currentSpeedDeg = 0.0f;
        tiltAxis.currentSpeedDeg = 0.0f;
    }
}

float MotionController::clampPan(float deg) const {
    if (!softLimitsActive) return deg;
    if (deg < panAxis.minLimitDeg) return panAxis.minLimitDeg;
    if (deg > panAxis.maxLimitDeg) return panAxis.maxLimitDeg;
    return deg;
}

float MotionController::clampTilt(float deg) const {
    if (!softLimitsActive) return deg;
    if (deg < tiltAxis.minLimitDeg) return tiltAxis.minLimitDeg;
    if (deg > tiltAxis.maxLimitDeg) return tiltAxis.maxLimitDeg;
    return deg;
}

bool MotionController::moveTo(float panDeg, float tiltDeg) {
    if (!drivesEnabled) setEnabled(true);

    float clampedPan = clampPan(panDeg);
    float clampedTilt = clampTilt(tiltDeg);

    panAxis.targetStep = (long)roundf(clampedPan * panAxis.stepsPerDeg);
    tiltAxis.targetStep = (long)roundf(clampedTilt * tiltAxis.stepsPerDeg);

    panAxis.mode = MODE_POSITION;
    tiltAxis.mode = MODE_POSITION;

    return (clampedPan == panDeg && clampedTilt == tiltDeg);
}

bool MotionController::moveRel(float deltaPanDeg, float deltaTiltDeg) {
    float newPan = getPanDeg() + deltaPanDeg;
    float newTilt = getTiltDeg() + deltaTiltDeg;
    return moveTo(newPan, newTilt);
}

void MotionController::setJogVelocity(float panDegPerSec, float tiltDegPerSec) {
    if (!drivesEnabled) setEnabled(true);

    // Clamp to max allowable speeds
    if (panDegPerSec > panAxis.maxSpeedDeg) panDegPerSec = panAxis.maxSpeedDeg;
    if (panDegPerSec < -panAxis.maxSpeedDeg) panDegPerSec = -panAxis.maxSpeedDeg;

    if (tiltDegPerSec > tiltAxis.maxSpeedDeg) tiltDegPerSec = tiltAxis.maxSpeedDeg;
    if (tiltDegPerSec < -tiltAxis.maxSpeedDeg) tiltDegPerSec = -tiltAxis.maxSpeedDeg;

    panAxis.targetSpeedDeg = panDegPerSec;
    tiltAxis.targetSpeedDeg = tiltDegPerSec;

    panAxis.mode = (fabs(panDegPerSec) > 0.001f || fabs(panAxis.currentSpeedDeg) > 0.001f) ? MODE_JOG : MODE_IDLE;
    tiltAxis.mode = (fabs(tiltDegPerSec) > 0.001f || fabs(tiltAxis.currentSpeedDeg) > 0.001f) ? MODE_JOG : MODE_IDLE;
}

void MotionController::stop() {
    // Decelerate to stop smoothly
    panAxis.targetSpeedDeg = 0.0f;
    tiltAxis.targetSpeedDeg = 0.0f;
    panAxis.targetStep = panAxis.currentStep;
    tiltAxis.targetStep = tiltAxis.currentStep;
    panAxis.mode = MODE_JOG;
    tiltAxis.mode = MODE_JOG;
}

void MotionController::emergencyStop() {
    // Instant stop and disable
    panAxis.currentSpeedDeg = 0.0f;
    tiltAxis.currentSpeedDeg = 0.0f;
    panAxis.targetSpeedDeg = 0.0f;
    tiltAxis.targetSpeedDeg = 0.0f;
    panAxis.targetStep = panAxis.currentStep;
    tiltAxis.targetStep = tiltAxis.currentStep;
    panAxis.mode = MODE_IDLE;
    tiltAxis.mode = MODE_IDLE;

    digitalWrite(panAxis.stepPin, LOW);
    digitalWrite(tiltAxis.stepPin, LOW);
    setEnabled(false);
}

void MotionController::setZero() {
    panAxis.currentStep = 0;
    panAxis.targetStep = 0;
    tiltAxis.currentStep = 0;
    tiltAxis.targetStep = 0;
    panAxis.currentSpeedDeg = 0.0f;
    tiltAxis.currentSpeedDeg = 0.0f;
    panAxis.mode = MODE_IDLE;
    tiltAxis.mode = MODE_IDLE;
}

void MotionController::setPosition(float panDeg, float tiltDeg) {
    panAxis.currentStep = (long)roundf(panDeg * panAxis.stepsPerDeg);
    panAxis.targetStep = panAxis.currentStep;
    tiltAxis.currentStep = (long)roundf(tiltDeg * tiltAxis.stepsPerDeg);
    tiltAxis.targetStep = tiltAxis.currentStep;
    panAxis.currentSpeedDeg = 0.0f;
    tiltAxis.currentSpeedDeg = 0.0f;
    panAxis.mode = MODE_IDLE;
    tiltAxis.mode = MODE_IDLE;
}

void MotionController::setMaxSpeed(float panDegPerSec, float tiltDegPerSec) {
    if (panDegPerSec > 0.1f && panDegPerSec <= ABSOLUTE_MAX_SPEED_PAN) {
        panAxis.maxSpeedDeg = panDegPerSec;
    }
    if (tiltDegPerSec > 0.1f && tiltDegPerSec <= ABSOLUTE_MAX_SPEED_TILT) {
        tiltAxis.maxSpeedDeg = tiltDegPerSec;
    }
}

void MotionController::setAcceleration(float panDegPerSec2, float tiltDegPerSec2) {
    if (panDegPerSec2 > 1.0f) panAxis.accelDeg = panDegPerSec2;
    if (tiltDegPerSec2 > 1.0f) tiltAxis.accelDeg = tiltDegPerSec2;
}

void MotionController::setStepsPerDegree(float panStepsPerDeg, float tiltStepsPerDeg) {
    if (panStepsPerDeg > 0.01f) {
        float currentDeg = getPanDeg();
        panAxis.stepsPerDeg = panStepsPerDeg;
        panAxis.currentStep = (long)roundf(currentDeg * panStepsPerDeg);
        panAxis.targetStep = panAxis.currentStep;
    }
    if (tiltStepsPerDeg > 0.01f) {
        float currentDeg = getTiltDeg();
        tiltAxis.stepsPerDeg = tiltStepsPerDeg;
        tiltAxis.currentStep = (long)roundf(currentDeg * tiltStepsPerDeg);
        tiltAxis.targetStep = tiltAxis.currentStep;
    }
}

void MotionController::setDirectionInvert(bool invertPan, bool invertTilt) {
    panAxis.dirInvert = invertPan;
    tiltAxis.dirInvert = invertTilt;
}
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

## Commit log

2026-08-28 feat: integrate Adafruit BNO055 9-DOF IMU sensor driver and live dashboard orientation card
2026-08-28 fix: resolve BNO055 I2C bus hang and stepper EMI interference
    - Remove Wire.begin() from BNO055_Driver::begin() — call it once in
    SensorManager::init() to prevent ATmega328P TWI state machine reset
    - Use I2C STOP condition instead of repeated-start to avoid TWI hang
    during BNO055 clock-stretching
    - Skip IMU I2C reads while stepper motors are actively moving to
    prevent EMI-corrupted zero readings; hold last good values
    - Add consecutive read failure tracking with auto-recovery
    - Add GET IMU diagnostic command with chip ID, mode, status registers
    - Add dashboard IMU mounting orientation remapping dropdown
    - Drain partial Wire buffer on failed multi-byte reads
    - Add 10Hz read rate to re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
    [BNO055_Driver.cpp, CommandParser.cpp, SensorManager.cpp]
2026-08-28 fix(dashboard): add under-base mounting orientation with inverted yaw and cardinal readout
    - Fix Heading showing East when pointed West due to inverted Z-axis on under-base mounting
    - Add 'Under-Base Rotated 90° (+Roll=Tilt, Flip E↔W)' as default mounting orientation
    - Add cardinal direction indicator badge (N, E, S, W, etc.) to IMU heading readout
    - Convert 0..360 yaw to -180..+180 Pan degrees when syncing steppers to IMU
    - Fix test mocks for native firmware testing
2026-08-28 fix(dashboard): use 180-deg heading offset instead of inverted yaw direction
    - Restore normal rotation sense so Pan- decreases heading as expected
    - Add 180-deg heading offset preset to resolve flipped North/South mounting
    - Invert pitch/roll sign appropriately for 180-deg flipped orientation
2026-08-28 docs: add comprehensive BNO055 operation, I2C fix, EMI mitigation, and mounting transformation documentation
2026-08-28 docs: update dashboard screenshot with live IMU ground truth and cardinal readout
2026-08-28 feat(visualizer): load and render custom Turret STL CAD models in 3D gimbal view
    - Add Three.js STLLoader integration
    - Load Turret_base.stl, Turret_top.stl, Turret_Shaft.stl, and gear assemblies
    - Seamlessly map CAD coordinates to kinematic Pan-Tilt joints
    - Add procedural geometry fallback
    [NEMA_motor_spacer.STL, Turret_Shaft.stl, Turret_base.stl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]
2026-08-28 fix(visualizer): align Turret_Shaft cross-mount platform exactly with physical photo reference
2026-08-28 fix(visualizer): flip Turret_Shaft right-side up along horizontal elevation axle
2026-08-28 docs: update dashboard screenshot with 3D CAD turret assembly rendering
2026-09-28 feat(calibration): 10-run BNO055 IMU ground truth calibration for pan & tilt
    - Calibrate Pan axis to 110.145 steps/deg (19.826:1 ratio, 39,652 steps/rev)
    - Calibrate Tilt axis to 59.267 steps/deg (10.668:1 ratio, 21,336 steps/rev)
    - Update Config.h and flash firmware
    - Add automated calibration suites (calibrate_10x.py, calibrate_dual_axis_imu.py, calibrate_pan_imu.py)
    - Add firmware upload helper and project backup utility
2026-09-29 feat(calibration): implement interactive 2-Point Manual Calibration Studio in dashboard
2026-09-29 docs: add comprehensive calibration procedures guide and update README
